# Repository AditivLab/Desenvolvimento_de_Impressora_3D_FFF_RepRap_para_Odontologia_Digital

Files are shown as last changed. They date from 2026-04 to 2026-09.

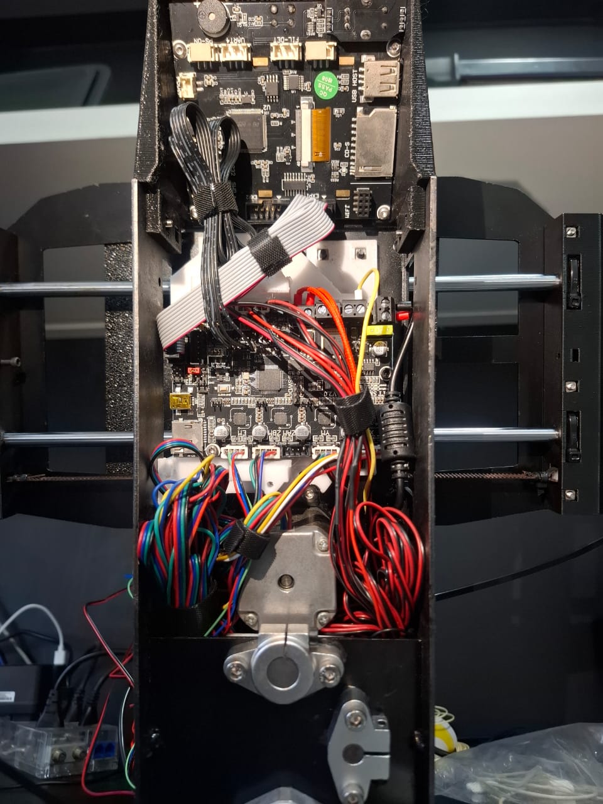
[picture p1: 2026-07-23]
INSTRUCOES DE MONTAGEM/organizacao_de_fios_eletronico.jpeg

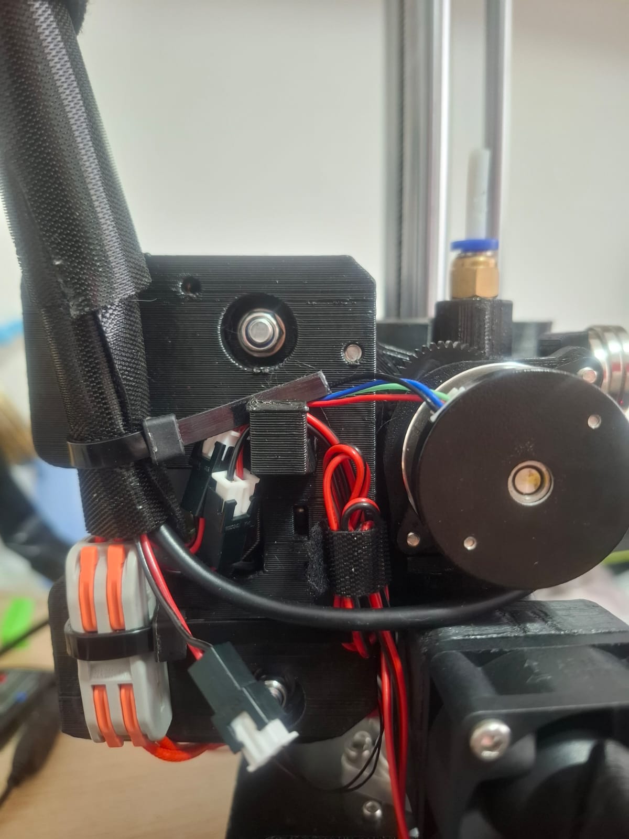
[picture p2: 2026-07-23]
INSTRUCOES DE MONTAGEM/organizacao_de_fios_feed.jpeg

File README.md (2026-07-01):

# **Desenvolvimento de impressora 3D FFF "RepRap" para Odontologia Digital**

Desenvolvimento de impressora 3D FFF com foco em odontologia digital, trazendo para comunidade odontológica uma plataforma aberta e colaborativo "RepRap", com o objetivo de promover o acesso livre à tecnologia.

Este projeto de impressora 3D FDM/FFF é um "remix" de diferentes máquinas com as quais tive a oportunidade de trabalhar. (Ultimaker de madeira, Printrbot Simple Metal, Proton, Ender PRO, 3D Lopes, Prusa MK3 e UPrint da Stratasys).

Após modificar impressoras de outras empresas para atender às nossas necessidades odontológicas, decidi criar meu próprio hardware para odontologia. Em 2026 o projeto teve o apoio da FUNDAÇÃO DE AMPARO A PESQUISA DO ESTADO DO RIO DE JANEIRO (https://www.faperj.br/)

impressora_views

REFERÊNCIAS:

http://www.reprap.org

https://reprap.org/wiki/Proton

abdrumm/printrbotdesigns

josefprusa/PrusaMendel

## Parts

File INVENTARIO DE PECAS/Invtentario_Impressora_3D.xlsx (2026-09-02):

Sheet: Orçamento Detalhado
ORÇAMENTO ESTIMADO DE PEÇAS - IMPRESSORA 3D
Cotação media de mercado de componentes (Valores em R$ BRL)
Categoria | Descrição da Peça / Componente | Qtd | Custo Unit. Estimado (R$) | Custo Total Estimado (R$) | Observações
PARAFUSOS | Parafuso M3 6mm (allen) | 2 | R$0.30 | R$0.60 | Aço inox / carbono
PARAFUSOS | Parafuso M3 10mm (allen) | 16 | R$0.35 | R$5.60 | Aço inox / carbono
PARAFUSOS | Parafuso M3 10mm CABEÇA CHATA | 1 | R$0.35 | R$0.35 | Aço inox / carbono
PARAFUSOS | Parafuso M3 15mm (allen) | 20 | R$0.40 | R$8.00 | Aço inox / carbono
PARAFUSOS | Parafuso M3 18 mm (allen) | 5 | R$0.45 | R$2.25 | Aço inox / carbono
PARAFUSOS | Parafuso M3 20 mm (allen) | 13 | R$0.45 | R$5.85 | Aço inox / carbono
PARAFUSOS | Parafuso M3 25 mm (allen) | 21 | R$0.50 | R$10.50 | Aço inox / carbono
PARAFUSOS | Parafuso M3 30 mm (allen) | 26 | R$0.60 | R$15.60 | Aço inox / carbono
PARAFUSOS | Parafuso M3 40 mm (allen) | 7 | R$0.80 | R$5.60 | Aço inox / carbono
PARAFUSOS | Parafuso M4 15 mm (allen) | 5 | R$0.50 | R$2.50 | Aço inox / carbono
PARAFUSOS | Parafuso M4 CABEÇA CHATA 30mm | 2 | R$0.70 | R$1.40 | Aço inox / carbono
PARAFUSOS | Parafuso M5 CABEÇA CHATA 30mm | 2 | R$0.90 | R$1.80 | Aço inox / carbono
PARAFUSOS | Parafuso M5 45mm | 2 | R$1.20 | R$2.40 | Aço inox / carbono
PARAFUSOS | Parafuso M5 20mm | 20 | R$0.70 | R$14.00 | Aço inox / carbono
PARAFUSOS | Parafuso M5 30mm | 10 | R$0.90 | R$9.00 | Aço inox / carbono
ESPAÇADORES | M3 DE COBRE COM 15MM DE CORPO E 5 MM DE ROSCA MACHO | 2 | R$2.50 | R$5.00 | Espaçador latão/cobre M3
ESPAÇADORES | M3 DE NYLON 10 MM DE CORPO E 5 MM DE ROSCA MACHO | 4 | R$1.00 | R$4.00 | Espaçador Nylon M3
PORCAS | Porca M3 TRAVANTE | 2 | R$0.40 | R$0.80 | Nyloc / Auto-travante
PORCAS | Porca M3 QUADRADA | 66 | R$0.30 | R$19.80 | Porca quadrada para perfil/peças
PORCAS | Porca M5 TRAVANTE | 22 | R$0.60 | R$13.20 | Nyloc / Auto-travante
PORCAS | Porca M5 | 10 | R$0.40 | R$4.00 | Porca sextavada padrão
ARRUELAS | Arruela M3 | 5 | R$0.15 | R$0.75 | Lisa de aço
ARRUELAS | Arruela M5 | 18 | R$0.25 | R$4.50 | Lisa de aço
EIXOS E FUSOS | Eixo 12 mm / 350mm comprimento (h7 cromo >0.15mm) | 2 | R$45.00 | R$90.00 | Eixo temperado/cromado
EIXOS E FUSOS | Eixo 8 mm/ 300 mm comprimento (h7 cromo >0.15mm) | 3 | R$28.00 | R$84.00 | Eixo temperado/cromado
EIXOS E FUSOS | Eixo 8 mm/ 250 mm comprimento (h7 cromo >0.15mm) | 2 | R$24.00 | R$48.00 | Eixo temperado/cromado
EIXOS E FUSOS | Parafuso TR8 293 mm (ou 300mm) Fuso Z | 1 | R$45.00 | R$45.00 | Fuso Trapezoidal TR8 com passo 8/4mm
EIXOS E FUSOS | Stop eixo y 8mm (Anel de trava/Trava de eixo) | 8 | R$4.50 | R$36.00 | Colar de trava de fuso/eixo 8mm
ROLAMENTOS E TRANSMISSÃO | pillow block sc8uu | 4 | R$14.00 | R$56.00 | Bloco de rolamento linear 8mm
ROLAMENTOS E TRANSMISSÃO | rolamento LM12UU | 2 | R$12.00 | R$24.00 | Rolamento linear 12mm
ROLAMENTOS E TRANSMISSÃO | rolamento LM8UU | 6 | R$7.50 | R$45.00 | Rolamento linear 8mm
ROLAMENTOS E TRANSMISSÃO | rolamento LMK8UU com flange | 4 | R$15.00 | R$60.00 | Rolamento linear com flange 8mm
ROLAMENTOS E TRANSMISSÃO | Mancal 12mm (KFL001 / SHF12) | 6 | R$16.00 | R$96.00 | Suporte / Mancal para eixo 12mm
ROLAMENTOS E TRANSMISSÃO | Mancal kfl08 | 1 | R$14.00 | R$14.00 | Mancal auto-alinhante 8mm
ROLAMENTOS E TRANSMISSÃO | lmk12uu com flange | 2 | R$22.00 | R$44.00 | Rolamento linear com flange 12mm
ROLAMENTOS E TRANSMISSÃO | Suporte Eixo Guia Linear 8mm Shf8 | 6 | R$9.00 | R$54.00 | Suporte guia SHF8
ROLAMENTOS E TRANSMISSÃO | Acoplamento connector D20 L25 (8mm para 5mm) Alumínio flex/rígido | 1 | R$18.00 | R$18.00 | Acoplador de eixo motor/fuso
ROLAMENTOS E TRANSMISSÃO | Castanha para fuso eixo Z Screw Shaft φ8, 278mm (lead 4) | 1 | R$15.00 | R$15.00 | Castanha de latão TR8
ROLAMENTOS E TRANSMISSÃO | Rolamento mr105zz | 6 | R$4.00 | R$24.00 | Rolamento de esferas 5x10x4mm
ROLAMENTOS E TRANSMISSÃO | Rolamento 625 (625zz) | 2 | R$5.00 | R$10.00 | Rolamento 5x16x5mm
ROLAMENTOS E TRANSMISSÃO | Polia gt2 20 teeth bore 5mm (diâmetro externo 16mm) | 2 | R$9.00 | R$18.00 | Polia GT2 20 dentes furo 5mm
ROLAMENTOS E TRANSMISSÃO | Correia eixo Y GT-2 belt, 2 mm pitch, 6 mm width (50 cm) | 2 | R$10.00 | R$20.00 | Correia sincronizada GT2 periódo 50cm
ROLAMENTOS E TRANSMISSÃO | Mola FIO 1.2 mm / diametro interno 5mm / altura 20-25mm | 1 | R$3.50 | R$3.50 | Mola de nivelamento / tensão
ROLAMENTOS E TRANSMISSÃO | Graxa branca de lítio (tubo/pote) | 1 | R$15.00 | R$15.00 | Lubrificante para eixos e fusos
MOTORES E ELETRÔNICA | Motor de Passo NEMA 17 Kysan 1124090 ou 1.5A-1.7A (4.2-4.5kg.cm) | 4 | R$65.00 | R$260.00 | Motores de passo para eixos X, Y, Z e Extrusora
MOTORES E ELETRÔNICA | Sensor Indutivo M12 4mm NPN NC 3 Fios 5V Lj12a3-4-z/bx-5v | 1 | R$28.00 | R$28.00 | Sensor auto-nivelamento de mesa
MOTORES E ELETRÔNICA | Endstop 125AVC 2A (MODELO NO.MP2344_all / Chave fim de curso) | 3 | R$5.00 | R$15.00 | Chaves fim de curso (X/Y/Z) - est. 3 unidades
MOTORES E ELETRÔNICA | Manta magnética 0.8 sem adesivo / Base de impressão | 1 | R$45.00 | R$45.00 | Manta magnética flexível
MOTORES E ELETRÔNICA | Tinta preta (Spray Automotivo Splaycolor 910) - Frasco 1 | 1 | R$24.00 | R$24.00 | Pintura de estruturas/peças
MOTORES E ELETRÔNICA | Tinta preta (Spray Automotivo Splaycolor 910) - Frasco 2 | 1 | R$24.00 | R$24.00 | Pintura de estruturas/peças
MOTORES E ELETRÔNICA | Placa Eletrônica SKR Mini E3 (BIGTREETECH) | 1 | R$260.00 | R$260.00 | Placa mãe 32 bits com drivers silenciosos
MOTORES E ELETRÔNICA | Engrenagem dentes feed MK8 drive gear | 1 | R$12.00 | R$12.00 | Tracionador de tracionamento de filamento
MOTORES E ELETRÔNICA | Cooler 3010 Back Fan 12V alta rotação 12000rpm | 1 | R$15.00 | R$15.00 | Ventoinha de refrigeração 30x30x10mm
MOTORES E ELETRÔNICA | Cooler 4010 Back Fan 12V 7500rpm | 1 | R$18.00 | R$18.00 | Ventoinha de refrigeração 40x40x10mm
MOTORES E ELETRÔNICA | Probe LJ18A3-8-Z/BY (distância 8mm) | 1 | R$35.00 | R$35.00 | Sensor indutivo alternativo/adicional
MOTORES E ELETRÔNICA | Colarinho fixação eixo z 12x8x20 | 8 | R$6.00 | R$48.00 | Anéis de trava/fixação eixo Z
MOTORES E ELETRÔNICA | Passador de fio / Organizador Fio Elétrico (metro) | 1 | R$12.00 | R$12.00 | Organizador de cabos / Tubo espiral
MOTORES E ELETRÔNICA | Serviço de impressão 3d de peças (16 horas estimado) | 16 | R$8.00 | R$128.00 | Valor/hora de impressão de peças estruturais
MOTORES E ELETRÔNICA | Frame / Estrutura rígida da impressora | 1 | R$280.00 | R$280.00 | Perfis de alumínio / painéis de corte de mdf/aço
MOTORES E ELETRÔNICA | Carretel de Filamento PLA / PETG 1kg | 1 | R$95.00 | R$95.00 | Insumo para testes e impressão inicial
CABOS E FONTE | Connector KK 2.5 mm fêmea 2 vias (com conector metálico) 5.5x2.1mm / 10A 100-220V | 1 | R$8.00 | R$8.00 | Conector de alimentação/sinal
CABOS E FONTE | Fio 22 AWG (Cabos gerais - preto, amarelo, branco, vermelho) - kit/metro | 10 | R$2.50 | R$25.00 | Fiação de sensores e motores (10m est.)
CABOS E FONTE | Fio 17 AWG (Cabo de força - preto e vermelho) - metro | 3 | R$4.50 | R$13.50 | Fiação de alta corrente/mesa (3m est.)
CABOS E FONTE | Fêmea P4 Conectores Jack Fêmea P4 5.5mm 2.1mm | 2 | R$4.00 | R$8.00 | Conectores Jack P4
CABOS E FONTE | Fonte Chaveada 12V 6A a 12V Modelo YU1206 | 1 | R$55.00 | R$55.00 | Fonte de alimentação 12V
TOTAL GERAL ESTIMADO |  |  |  | R$2365.50

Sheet: Resumo por Categoria
RESUMO FINANCEIRO POR CATEGORIA
Categoria de Componentes | Custo Total Estimado (R$) | % do Orçamento
PARAFUSOS | R$85.45 | 3.6%
ESPAÇADORES | R$9.00 | 0.4%
PORCAS | R$37.80 | 1.6%
ARRUELAS | R$5.25 | 0.2%
EIXOS E FUSOS | R$303.00 | 12.8%
ROLAMENTOS E TRANSMISSÃO | R$516.50 | 21.8%
MOTORES E ELETRÔNICA | R$1299.00 | 54.9%
CABOS E FONTE | R$109.50 | 4.6%
TOTAL | R$2365.50 | 100.0%

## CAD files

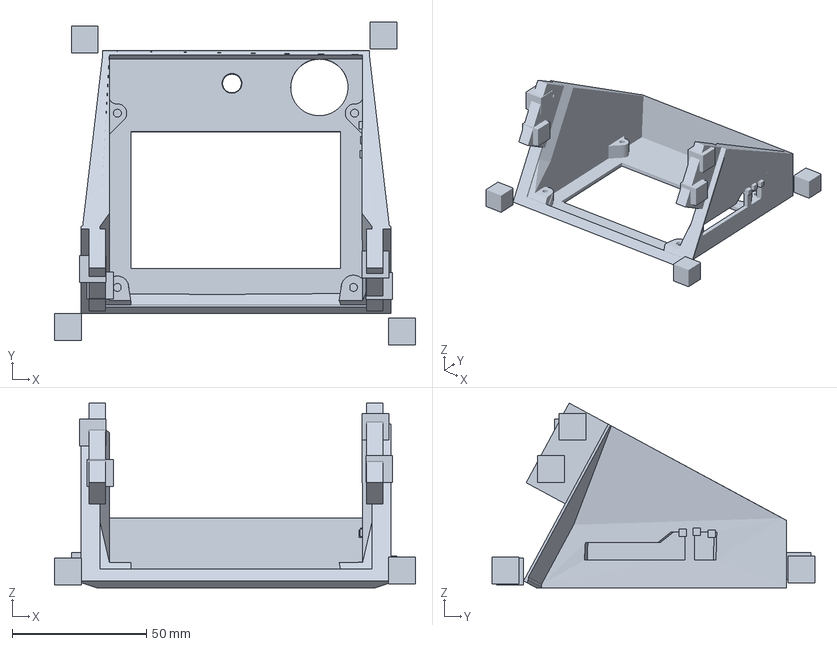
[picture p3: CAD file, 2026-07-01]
GCODE E CAD/eletronico/lcd/suporte lcd 008.3mf
134.5 x 120.2 x 68.9 mm

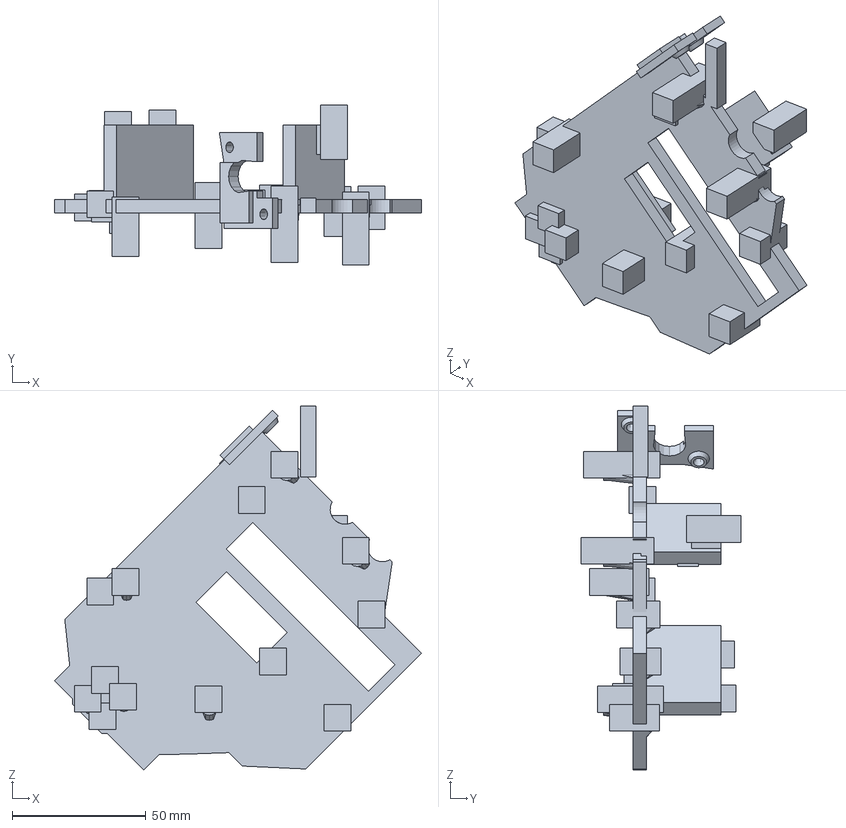
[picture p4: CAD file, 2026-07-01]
GCODE E CAD/eletronico/placa mae/suporte skr mini-228g-7h-29m 003.3mf
137.0 x 59.6 x 135.8 mm

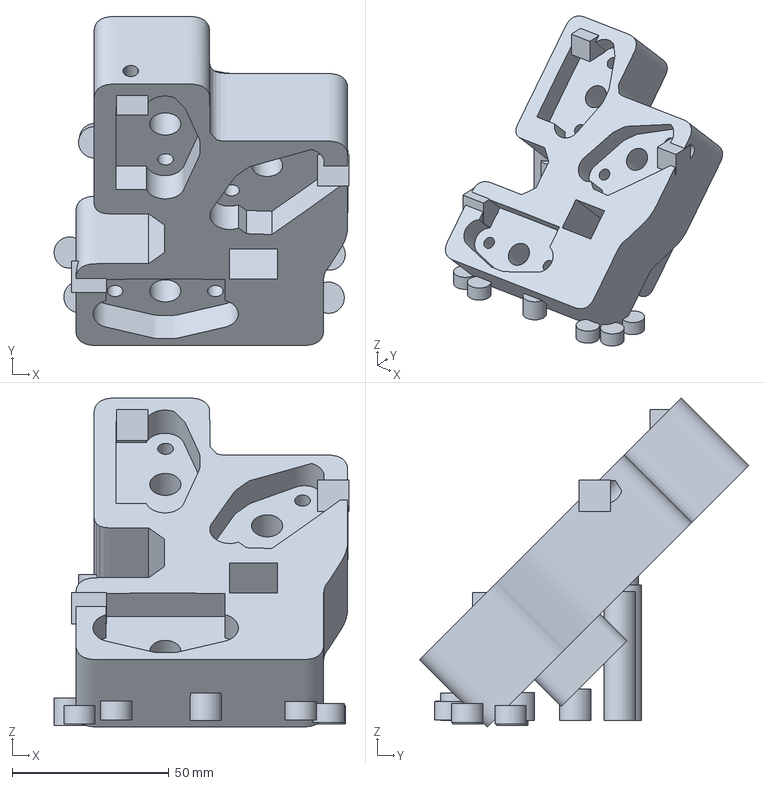
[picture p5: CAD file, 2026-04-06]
GCODE E CAD/frame/back impresso/PS_frame impresso back para eixo 8mm 004.3mf
94.0 x 105.0 x 104.9 mm

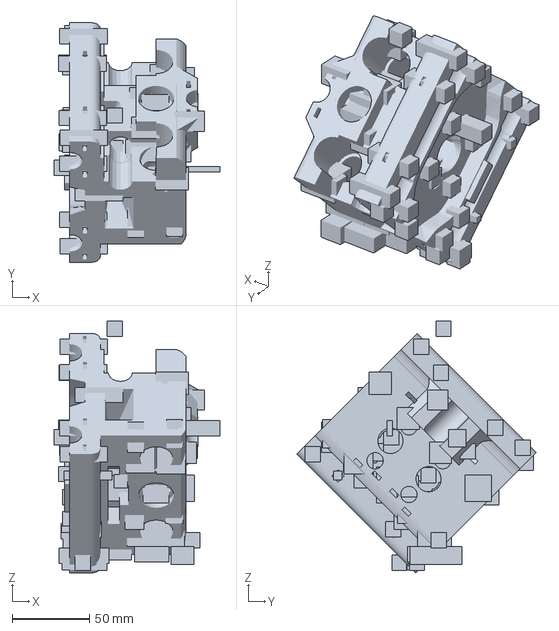
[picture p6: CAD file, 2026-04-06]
GCODE E CAD/frame/central/CFFFP_frame central impresso eixo 8y 007.3mf
107.5 x 155.3 x 163.3 mm

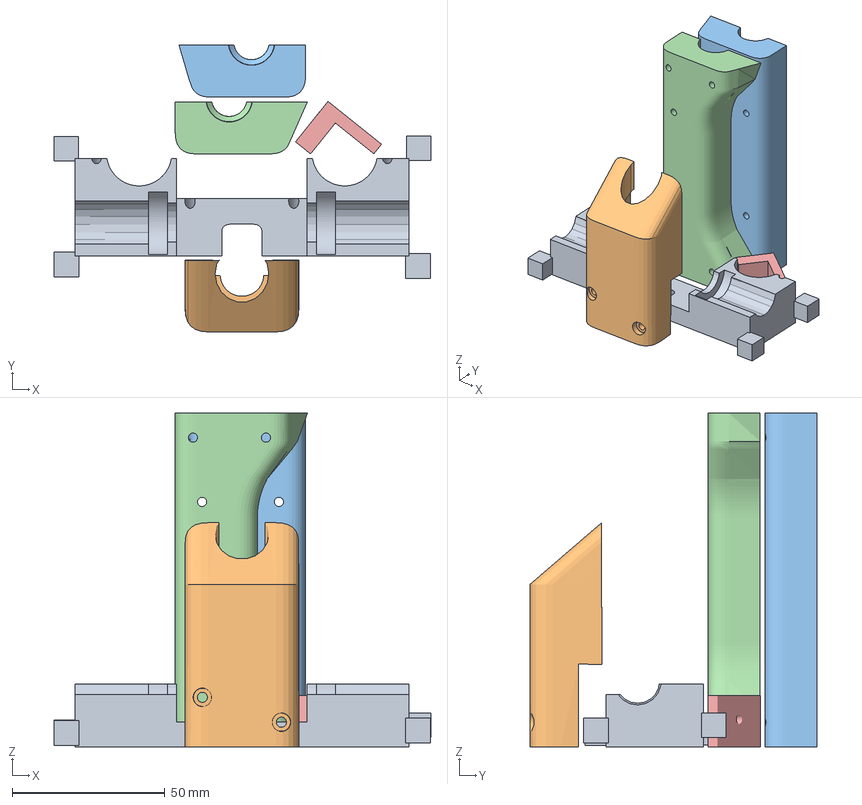
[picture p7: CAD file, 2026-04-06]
GCODE E CAD/frame/central/peças acessorias/CFFFP_peças acessorias do frame central 003.3mf
123.2 x 93.8 x 109.1 mm
fixacao eixo y e Z back.stl
fixacao_3o_eixo_Z_8mm.stl
tampa y eixo central impresso sup.stl
tempo y eixo central impresso inf.stl
STOP Y001.stl

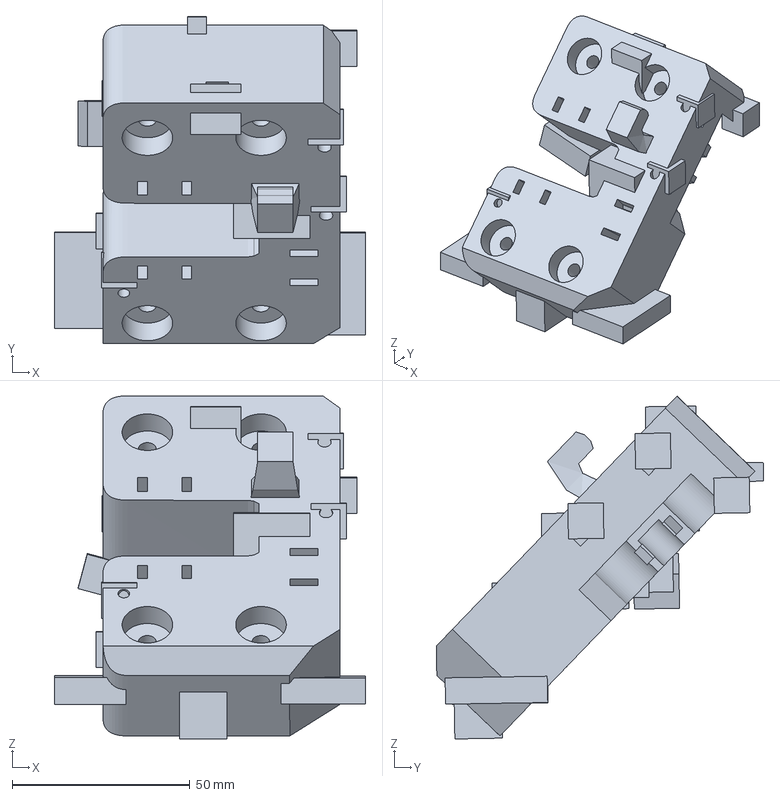
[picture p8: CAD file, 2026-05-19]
GCODE E CAD/frame/front/CFFFP_frame impresso feed com fixacao para bico007.3mf
87.6 x 92.2 x 96.6 mm

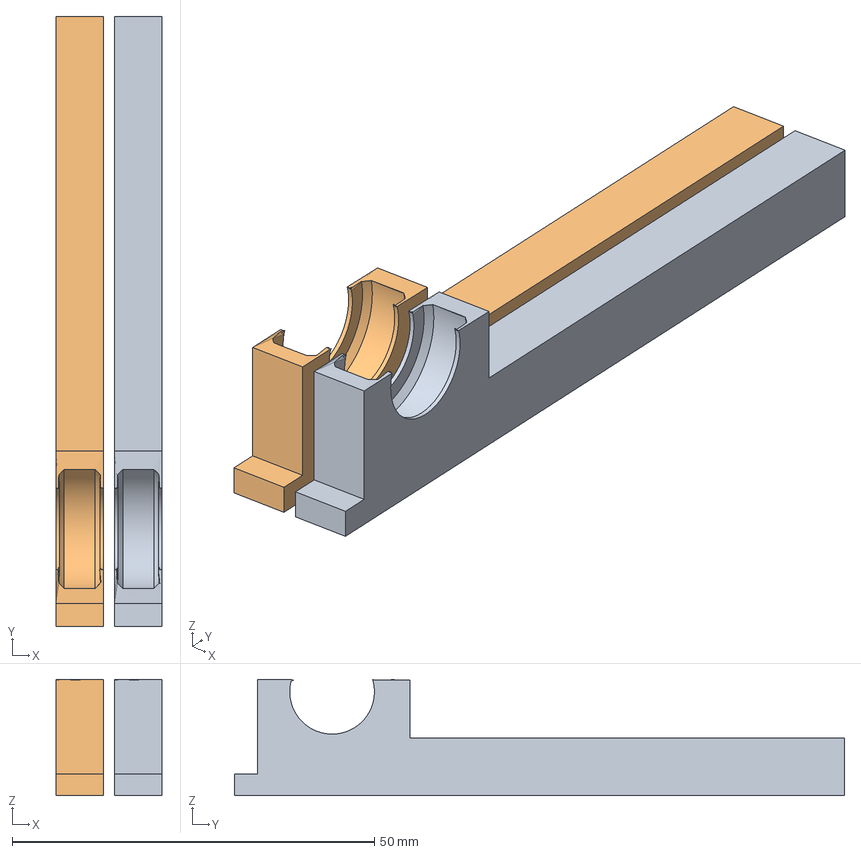
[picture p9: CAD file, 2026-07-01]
GCODE E CAD/guia para montagem correia eixo Y/PS_guia de montagem rolamento Y 001.3mf
14.7 x 84.2 x 16.0 mm
guia de montagem rolamento Y.stl
guia de montagem rolamento Y.stl(1)

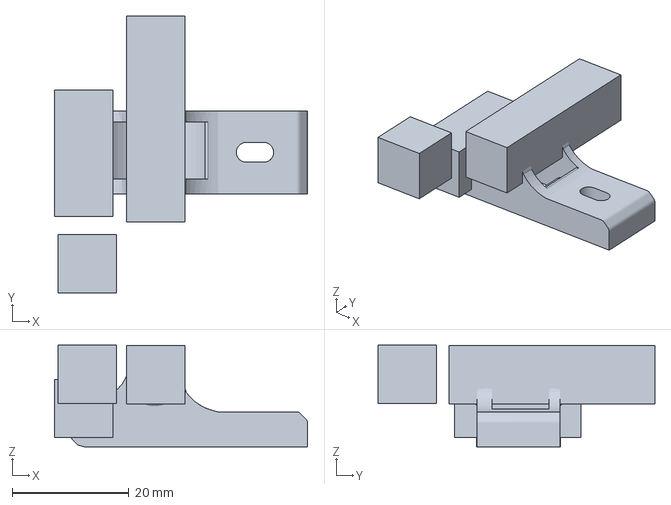
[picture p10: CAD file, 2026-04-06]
GCODE E CAD/hotend e feed/ALAVANCA/alavanca reforcada/CFFFP_PS_alavanca reforcada 001.3mf
43.4 x 47.4 x 17.4 mm

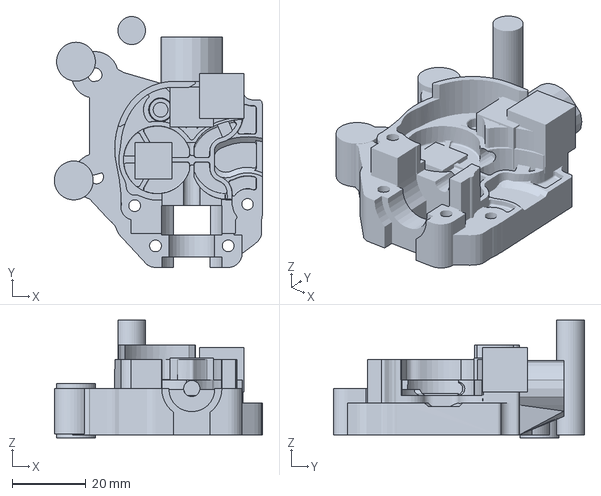
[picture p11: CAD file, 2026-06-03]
GCODE E CAD/hotend e feed/back/PS_extrusor leve back edit v008.3mf
56.5 x 68.1 x 31.9 mm

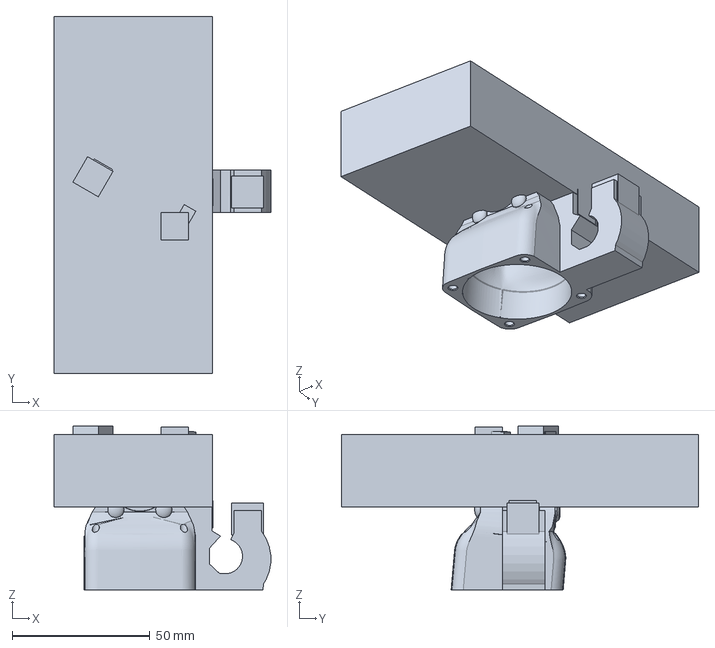
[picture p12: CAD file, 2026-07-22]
GCODE E CAD/hotend e feed/cooler tambor/PS_cooler tambor 004.3mf
78.7 x 129.7 x 59.6 mm

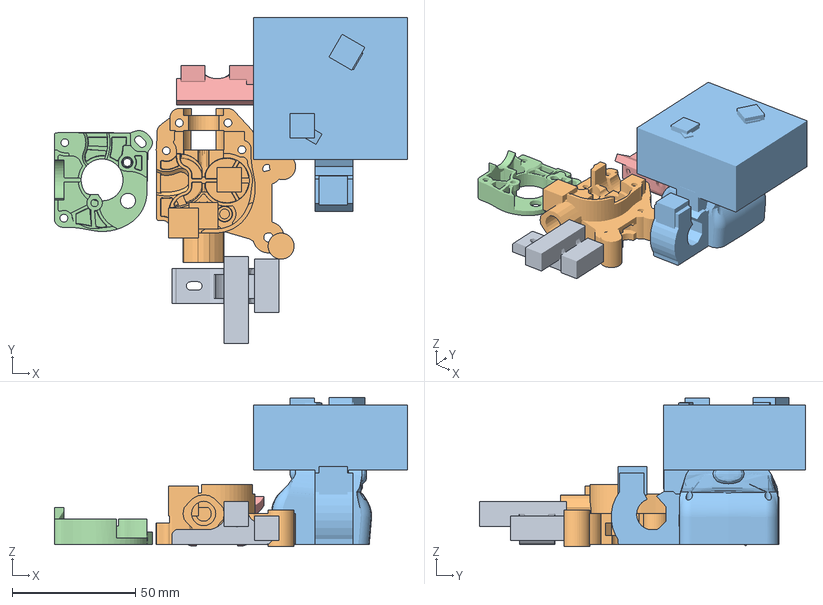
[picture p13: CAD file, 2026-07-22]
GCODE E CAD/hotend e feed/feed completo/PS_CFFFP_feed completo 003.3mf
143.1 x 132.2 x 60.4 mm
alavanca reforcada 004.stl
extrusor leve back edit 017.stl
cooler tambor com probe fino de 12mm 006.stl
frontal feed 011.stl
trava hotend 006.stl

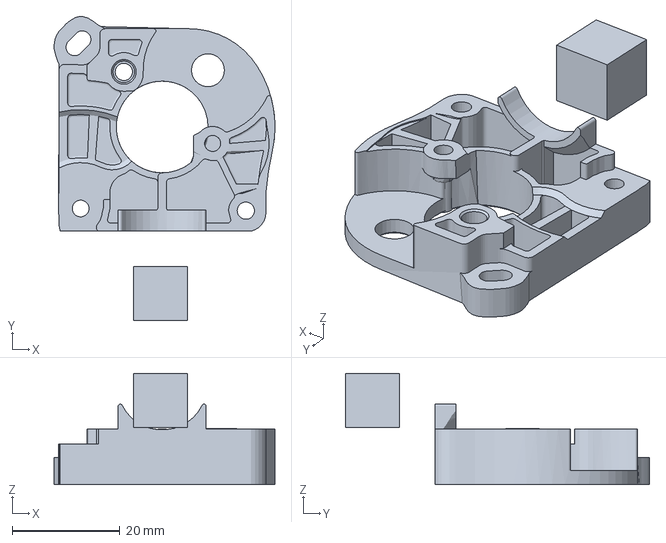
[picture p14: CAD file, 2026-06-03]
GCODE E CAD/hotend e feed/frontal feed/tampa frontal feed 004.3mf
40.9 x 56.3 x 20.6 mm

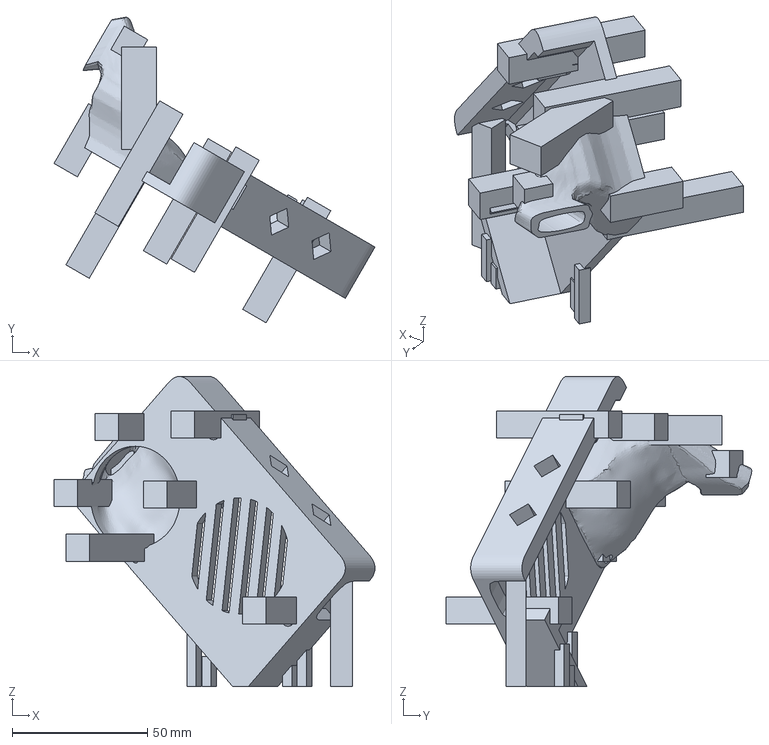
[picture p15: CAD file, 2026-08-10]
GCODE E CAD/hotend e feed/tampa cooler impressao/CFFFP_cover fios feed com cooler impressao 015.3mf
118.8 x 113.1 x 114.7 mm

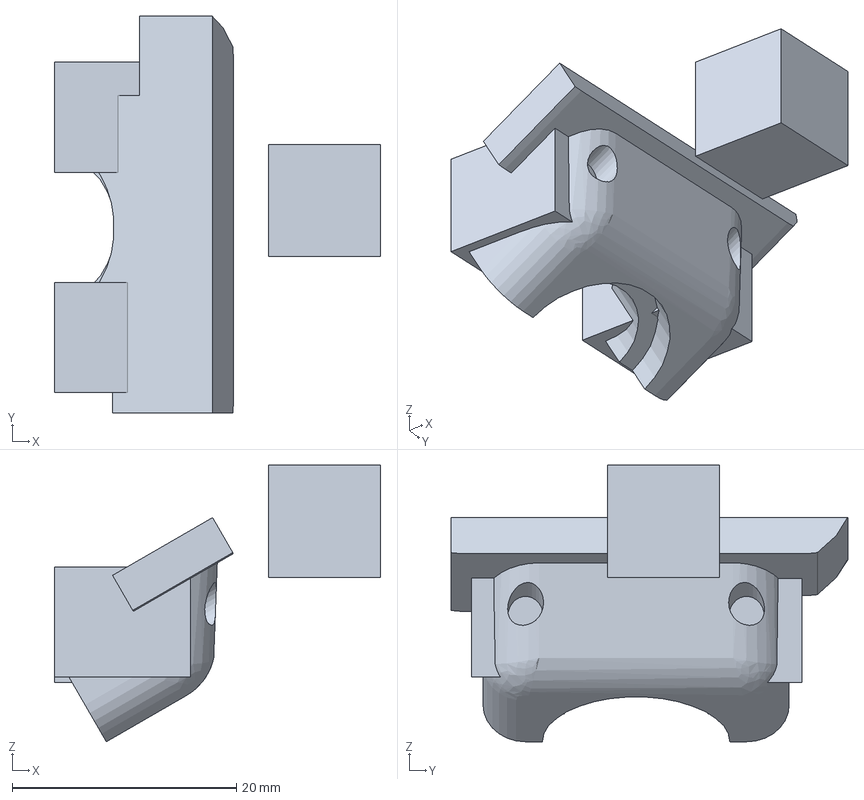
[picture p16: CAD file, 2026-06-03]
GCODE E CAD/hotend e feed/trava hotend/PS_CFFFP_trava hotend 004.3mf
29.1 x 35.4 x 24.7 mm

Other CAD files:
GCODE E CAD/MESA/braco/braço_fixador_da_mesa right 002.stl
GCODE E CAD/MESA/stop mesa limite/CFFFP_limite mesa 004.3mf
GCODE E CAD/spool holder/CFFFP_spool holder 002.3mf
GCODE E CAD/travas para porcas e suportes/CFFFP_suportes eixos e endstop 003.3mf
GCODE E CAD/MESA/braco/CFFFP_braço_fixador_da_mesa 006.3mf
GCODE E CAD/MESA/braco/braço_fixador_da_mesa left 002.stl
GCODE E CAD/MESA/stop mesa limite/limite mesa 003.stl

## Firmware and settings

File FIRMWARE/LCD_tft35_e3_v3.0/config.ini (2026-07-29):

#--------------------------------------------------------------------
#
# DEFAULT CONFIG FILE FOR BigTreeTech TFT CONTROLLERS
#
#--------------------------------------------------------------------


#--------------------------------------------------------------------
# Supported TFT Variants
#--------------------------------------------------------------------
#
# BIGTREE_TFT24_V1_1    / BIGTREE_TFT28_V1_0 / BIGTREE_TFT28_V3_0
# BIGTREE_TFT35_V1_0    / BIGTREE_TFT35_V1_1 / BIGTREE_TFT35_V1_2
# BIGTREE_TFT35_V2_0    / BIGTREE_TFT35_V3_0 / BIGTREE_TFT35_E3_V3_0
# BIGTREE_TFT35_B1_V3_0 / BIGTREE_TFT43_V3_0 / BIGTREE_TFT50_V3_0
# BIGTREE_TFT70_V3_0
#
# BIGTREE_GD_TFT24_V1_1    / BIGTREE_GD_TFT35_V2_0    / BIGTREE_GD_TFT35_V3_0
# BIGTREE_GD_TFT35_E3_V3_0 / BIGTREE_GD_TFT35_B1_V3_0 / BIGTREE_GD_TFT43_V3_0
# BIGTREE_GD_TFT50_V3_0    / BIGTREE_GD_TFT70_V3_0
#
# MKS_TFT28_V3_0 / MKS_TFT28_V4_0 / MKS_TFT28_NEW_GENIUS
# MKS_TFT32_V1_3 / MKS_TFT32_V1_4 / MKS_TFT32L_V3_0
# MKS_TFT35_V1_0
#
# MKS_GD_TFT28_V1_2_4
#
# Firmware source: https://github.com/bigtreetech/BIGTREETECH-TouchScreenFirmware


#--------------------------------------------------------------------
# Supported Marlin Firmware Versions
#--------------------------------------------------------------------
#
# Minimum Marlin firmware version: 2.1.1
# Distribution date: 2022-09-22
# Firmware source: https://github.com/MarlinFirmware/Marlin/releases
#
# To use all the features and functionalities supported by the TFT,
# the following options must be enabled in Marlin firmware.
#
# General options which MUST be always activated:
#   EEPROM_SETTINGS (in Configuration.h)
#   BABYSTEPPING (in Configuration_adv.h)
#   AUTO_REPORT_TEMPERATURES (in Configuration_adv.h)
#   AUTO_REPORT_POSITION (in Configuration_adv.h)
#   EXTENDED_CAPABILITIES_REPORT (in Configuration_adv.h)
#   M115_GEOMETRY_REPORT (in Configuration_adv.h)
#   M114_DETAIL (in Configuration_adv.h)
#   REPORT_FAN_CHANGE (in Configuration_adv.h)
#
# Options to support printing from onboard media:
#   SDSUPPORT (in Configuration.h)
#   LONG_FILENAME_HOST_SUPPORT (in Configuration_adv.h)
#   AUTO_REPORT_SD_STATUS (in Configuration_adv.h)
#   SDCARD_CONNECTION ONBOARD (in Configuration_adv.h)
#
# Options to support dialog with host:
#   EMERGENCY_PARSER (in Configuration_adv.h)
#   SERIAL_FLOAT_PRECISION 4 (in Configuration_adv.h)
#   HOST_ACTION_COMMANDS (in Configuration_adv.h)
#   HOST_PROMPT_SUPPORT (in Configuration_adv.h)
#   HOST_STATUS_NOTIFICATIONS (in Configuration_adv.h)
#
# Options to support M73 with host:
#   Options to support dialog with host (as pre requisite)
#   SET_PROGRESS_MANUALLY (in Configuration_adv.h)
#   M73_REPORT (in Configuration_adv.h)
#
# Options to support ADVANCED_OK with host:
#   ADVANCED_OK (in Configuration_adv.h)
#
# Options to support M600 with host & (Un)Load menu:
#   Options to support dialog with host (as pre requisite)
#   NOZZLE_PARK_FEATURE (in Configuration.h)
#   ADVANCED_PAUSE_FEATURE (in Configuration_adv.h)
#   PARK_HEAD_ON_PAUSE (in Configuration_adv.h)
#   FILAMENT_LOAD_UNLOAD_GCODES (in Configuration_adv.h)
#
# Options to fully support Bed Leveling menu:
#   Z_MIN_PROBE_REPEATABILITY_TEST (in Configuration.h)
#   G26_MESH_VALIDATION (in Configuration.h)
#   Z_STEPPER_AUTO_ALIGN (in Configuration_adv.h)


#--------------------------------------------------------------------
# General Settings
#--------------------------------------------------------------------

#### Serial Ports (Primary and Supplementary)
# Serial ports connected to devices such as Printer, ESP3D, OctoPrint and other Controllers.
# In order to successfully establish a communication through a serial port, set a baudrate
# matching the baudrate configured on the connected device.
# Disable the serial port when it is not in use and/or not connected to a device (floating) to
# avoid to receive and process wrong data due to possible electromagnetic interference (EMI).
#
# NOTES:
#   - Serial port P1 is the primary serial connection to the printer and cannot be disabled.
#   - A baudrate of 250000 works in most cases, but you can try a lower speed if you
#     commonly experience drop-outs during host printing.
#     You may try up to 1000000 to speed up SD file transfer.
#
#   Format: [serial_port: P1:<baudrate> P2:<baudrate> P3:<baudrate> P4:<baudrate>
#   Target port: P1: Printer
#                P2: WIFI    (e.g. ESP3D)
#                P3: UART 3  (e.g. OctoPrint)
#                P4: UART 4
#   Value range: P1: [min: 1, max: 11]
#                P2: [min: 0, max: 11]
#                P3: [min: 0, max: 11]
#                P4: [min: 0, max: 11]
#   Options: [OFF (port disabled): 0, 2400: 1, 9600: 2, 19200: 3, 38400: 4, 57600: 5, 115200: 6, 230400: 7, 250000: 8, 500000: 9, 921600: 10, 1000000: 11]
serial_port:P1:6 P2:0 P3:0 P4:0
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

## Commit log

2026-04-06 codigos de impressao das partes
    [CFFFP_Ender-suporte skr mini-228g-7h-29m 002.3mf, CFFFP_PS_alavanca reforcada 001.3mf, CFFFP_braço_fixador_da_mesa 004.3mf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]
2026-05-19 add referencias e inspiracoes
    [CFFFP_Ender-suporte skr mini-228g-7h-29m 002.3mf, CFFFP_PS_alavanca reforcada 001.3mf, CFFFP_braço_fixador_da_mesa 004.3mf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]
2026-06-03 ajuste projeto feed
    [CFFFP_suportes eixos e endstop 002.3mf, CFFFP_suportes eixos e endstop 003.3mf, CFFFP_trava hotend 003.3mf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]
2026-06-03 atualiz feed
    [CFFFP_feed completo 001.3mf, CFFFP_feed completo 002.3mf]
2026-06-08 Update README.md
    melhora descricao para home
2026-07-01 ajuste de gcode
    s
2026-07-01 ajuste de gcode
    [CFFFP_Ender-suporte skr mini-228g-7h-29m 002.3mf, PS_guia de montagem rolamento Y 001.3mf, PS_pe de apoio 001.3mf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]
2026-07-22 inventario v001
    [inventario 2 mercado livre.xlsx]
2026-07-22 atualizacoa de gcode
    [CFFFP_cover fios feed com cooler impressao 005.3mf, CFFFP_cover fios feed com cooler impressao 011.3mf]
2026-07-22 nova orquivo e comentario
    [CFFFP_feed completo 002.3mf, PS_CFFFP_feed completo 003.3mf, PS_cooler tambor 003.3mf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]
2026-07-25 atualizacao gcodes
    [CFFFP_cover fios feed com cooler impressao 011.3mf, CFFFP_cover fios feed com cooler impressao 012.3mf]
2026-08-12 inventario att e montagem att
    [inventario 2 mercado livre.xlsx]
2026-08-26 Atualização das instruções de montagem
    [inventario 2 mercado livre.xlsx]
2026-09-02 inventario att
    [Invtentario_Impressora_3D.xlsx, inventario 2 mercado livre.xlsx]
